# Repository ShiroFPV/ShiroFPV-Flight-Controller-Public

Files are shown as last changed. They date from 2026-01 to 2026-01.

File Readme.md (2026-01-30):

## 📖 Credits 
This project was heavily inspired by the amazing work of AcciFPV. Their creativity and open sharing within the FPV community motivated me to start developing my own hardware. While this design is fully original, AcciFPV’s approach and passion for innovation definitely sparked many of the ideas behind it. Huge thanks to them for contributing so much to the FPV scene — check out their projects for more awesome stuff!
[Github](https://gist.github.com/jesuslg123)
[AcciFPV Flight Controller](https://oshwlab.com/jesuslg123/f4-v1)

## 📖 Documentation

This repository includes a full website with detailed documentation. You can view the live documentation here:

[Website](https://shirofpv.github.io/ShiroFPV-Flight-Controller-Public/Website/index.html)

The documentation covers:
* **Hardware Specifications:** A breakdown of components.
* **Software & Firmware:** Information on compatible firmware (Betaflight) and how to get the latest builds.
* **Setup Guide:** A step-by-step guide to flashing firmware, and getting your drone in the air.

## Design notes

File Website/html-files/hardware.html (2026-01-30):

ShiroFPV

# Hardware Specifications

Technical details and component information

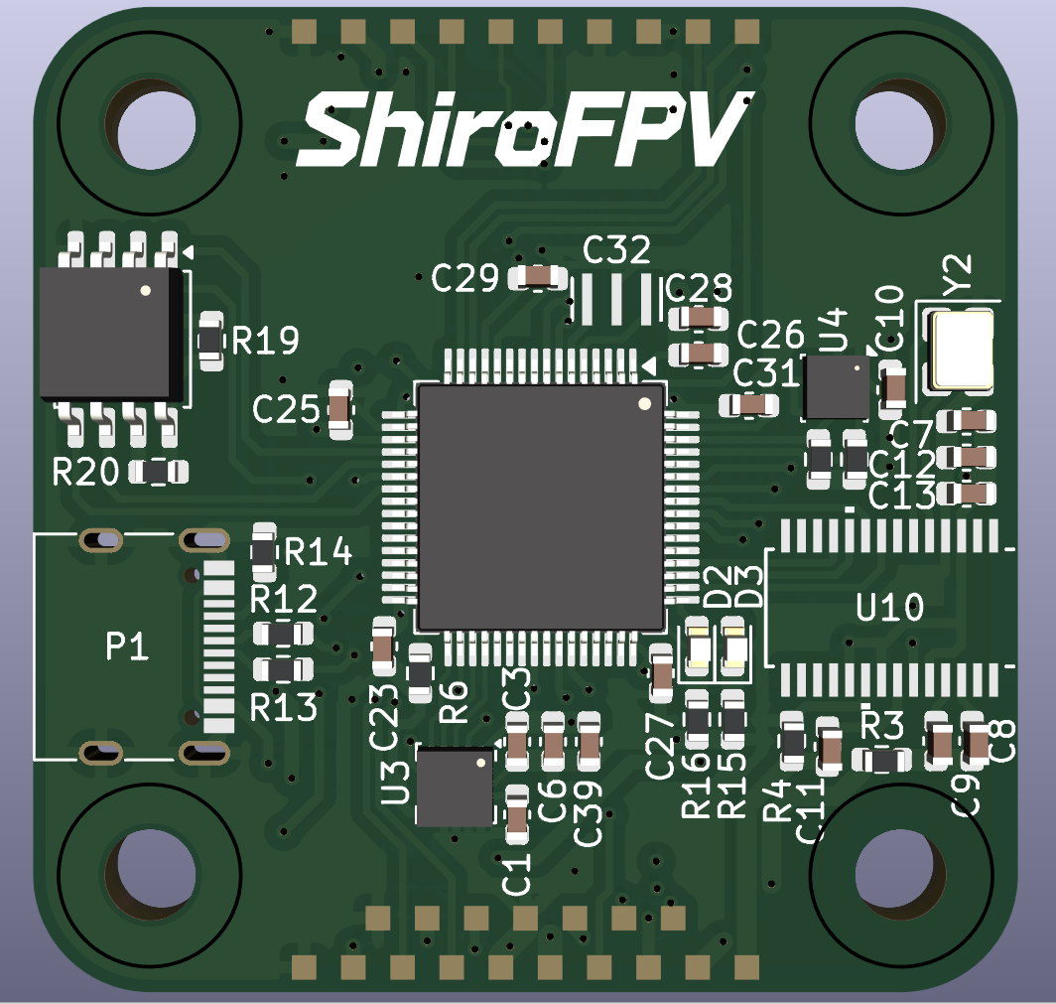
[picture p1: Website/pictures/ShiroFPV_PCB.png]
Betaflight Logo


### Microcontroller

High-performance MCU with fast processing capabilities for real-time flight control

### IMU Sensor

Precision gyroscope and barometer for accurate orientation tracking

### Form Factor

Compact design compatible with modern FPV frames (30x30mm mounting)

### Input Voltage

Wide voltage input range with onboard regulation for stable operation

## Key Features

- High-speed gyro: Fast sampling rates for smooth, precise control
- Onboard voltage regulation: Stable power delivery to all components
- USB connectivity: Easy configuration and firmware updates
- Multiple UART ports: Connect receivers, GPS, telemetry, and more
- PWM outputs: Drive ESCs with configurable protocols
- LED indicators: Visual status feedback for easy troubleshooting
- Mounting holes: Standard mounting pattern for easy installation
- Durable PCB: High-quality materials for long-term reliability

## PCB Design

The ShiroFPV flight controller features a carefully optimized PCB layout with attention to signal integrity, power distribution, and electromagnetic compatibility. All design files are available on GitHub for those interested in manufacturing their own boards or learning from the design.

## Build Quality

Each component is carefully selected for performance and reliability. The board undergoes thorough testing to ensure it meets high standards for FPV flight applications.

© 2026 ShiroFPV. Open Source Hardware Project.

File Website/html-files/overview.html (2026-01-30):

ShiroFPV

# Overview

Everything you need to know about the ShiroFPV Flight Controller

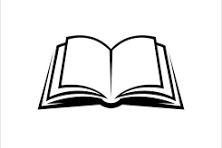
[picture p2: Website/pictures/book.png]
Book


## What is ShiroFPV?

The ShiroFPV Flight Controller is a high-performance, open-source flight control system designed by an FPV pilot for FPV pilots. Built with modern components and support for the Betaflight firmware, it delivers exceptional flight characteristics and reliability.

Key Philosophy: ShiroFPV combines professional-grade performance with open-source accessibility, allowing pilots to fully understand and customize their flight control system.

## Core Features

- High-Speed Processing: Fast loop times for precise control and minimal latency
- Robust Design: Built to withstand crashes and harsh flying conditions
- Betaflight Compatible: Full support for the most popular FPV firmware
- Compact Form Factor: Optimized size for modern racing and freestyle frames
- Open Source: Complete hardware designs and documentation available on GitHub
- Community Driven: Active development with regular updates and improvements

## Target Audience

ShiroFPV is designed for:

- FPV racing pilots seeking competitive performance
- Freestyle pilots who demand reliable, responsive control
- DIY enthusiasts interested in open-source hardware
- Developers wanting to customize and extend flight controller capabilities

## Project Goals

The ShiroFPV project aims to provide a completely transparent, high-quality flight controller that empowers users to understand, modify, and improve their flight systems. By keeping everything open source, we foster innovation and community collaboration.

© 2026 ShiroFPV. Open Source Hardware Project.

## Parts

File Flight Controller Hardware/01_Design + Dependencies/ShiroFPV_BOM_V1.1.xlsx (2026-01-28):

Quantity | Footprint | Supplier | Supplier Part Number | Manufacturer | Manufacturer Part Number
18 | Capacitor_SMD:C_0603_1608Metric | LCSC | C327087 | YAGEO | CC0603JRX7R8BB104
1 | Capacitor_SMD:C_0603_1608Metric | LCSC | C3894265 | KEMET | C0603C103F3GECAUTO
2 | Capacitor_SMD:C_0603_1608Metric | LCSC | C106248 | GENERIC | 1uF_0603_X7R_16V
4 | Capacitor_SMD:C_0603_1608Metric | LCSC | C403725 | muRata | GRM31CR61E476ME44L
2 | Capacitor_SMD:C_1206_3216Metric | LCSC | C89632 | SAMSUNG | CL31B106KBHNNNE
1 | Capacitor_SMD:C_0603_1608Metric | LCSC | C519513 | YAGEO | CC0603JRX7R9BB101
1 | Capacitor_SMD:C_0603_1608Metric | LCSC | C519515 | YAGEO | CC0603JRX7R9BB151
1 | All_Own_Symbols:8MHz-Osciallator.kicad_sym | LCSC | C907975 | muRata | CSTNE8M00G520000R0
1 | Capacitor_SMD:C_0603_1608Metric | LCSC | C106213 | YEGEO | CC0603KRX5R6BB225
1 | Diode_SMD:D_SOD-323_HandSoldering | LCSC | C131828 | LRC | LM3Z10VT1G
1 | LED_SMD:LED_0603_1608Metric | LCSC | C72038 | EVERLIGHT | 19-213/Y2C-CQ2R2L/3T(CY)
1 | LED_SMD:LED_0603_1608Metric | LCSC | C2986058 | EVERLIGHT | 19-217/BHC-ZL1M2RY/6T
1 | Package_TO_SOT_SMD:SOT-23 | LCSC | C552889 | Nexperia | PMEG4005CT,215
1 | Fuse:Fuse_1206_3216Metric | LCSC | C163128 | TA-I Tech | CFS12V3T5R0
1 | Inductor_SMD:L_APV_APH0412 | LCSC | C351093 | YJYCOIN | YSPI0420-100M
1 | Inductor_SMD:L_APV_APH0412 | LCSC | C497861 | YJYCOIN | YSPI0530-150M
1 | Connector_USB:USB_C_Receptacle_G-Switch_GT-USB-7010ASV | LCSC | C2988369 | G-Switch | GT-USB-7010ASV
1 | Package_TO_SOT_SMD:SOT-23 | LCSC | C15127 | Alpha & Omega Semicon | AO3401A
1 | Package_TO_SOT_SMD:SOT-23 | LCSC | C20917 | Alpha & Omega Semicon | AO3400A
1 | Package_TO_SOT_SMD:SOT-323_SC-70 | LCSC | C148104 | CJ | BC817W
3 | Resistor_SMD:R_0603_1608Metric | LCSC | C14675 | YAGEO | RC0603FR-07100KL
1 | Resistor_SMD:R_0603_1608Metric | LCSC | C22548 | YAGEO | RC0603FR-0712K3L
2 | Resistor_SMD:R_0603_1608Metric | LCSC | C112309 | YAGEO | RC0603FR-0775RL
6 | Resistor_SMD:R_0603_1608Metric | LCSC | C98220 | YAGEO | RC0603FR-0710KL
1 | Resistor_SMD:R_0603_1608Metric | LCSC | C114631 | YAGEO | RC0603FR-076K2L
2 | Resistor_SMD:R_0603_1608Metric | LCSC | C107701 | YAGEO | RC0603FR-0722RL
1 | Resistor_SMD:R_0603_1608Metric | LCSC | C105580 | YAGEO | RC0603FR-075K1L
2 | Resistor_SMD:R_0603_1608Metric | LCSC | C114608 | YAGEO | RC0603FR-07150RL
2 | Resistor_SMD:R_0603_1608Metric | LCSC | C114662 | YAGEO | RC0603FR-072K2L
1 | Resistor_SMD:R_0603_1608Metric | LCSC | C105576 | YAGEO | RC0603FR-072KL
1 | Resistor_SMD:R_0603_1608Metric | LCSC | C99782 | YAGEO | RC0603FR-074K7L
1 | Resistor_SMD:R_0603_1608Metric | LCSC | C114610 | YAGEO | RC0603FR-0718KL
1 | Package_QFP:LQFP-64_10x10mm_P0.5mm | LCSC | C3029577 | ARTERY | AT32F435RGT7
1 | Package_LGA:LGA-16_3x3mm_P0.5mm_LayoutBorder3x5y | LCSC | C97633 | TDK InvenSense | ICM-20602
1 | Package_LGA:Bosch_LGA-8_2.5x2.5mm_P0.65mm_ClockwisePinNumbering | LCSC | C92489 | BOSCH | BME280
2 | Package_TO_SOT_SMD:SOT-23-6 | LCSC | C311983 | TI | TPS54302DDCR
1 | Package_TO_SOT_SMD:SOT-23-5 | LCSC | C47773 | RICHTEK | RT9013-33GB
1 | Package_SO:SOIC-8_5.3x5.3mm_P1.27mm | LCSC | C97521 | Winbond | W25Q128JVSIQ
1 | All_Own_Symbols:AT7456 | LCSC | C82351 | ZHONGKEWEI | AT7456E
1 | Crystal:Crystal_SMD_3225-4Pin_3.2x2.5mm | LCSC | C164057 | ZHONGKEWEI | TAXM27M4RFBCCT2T

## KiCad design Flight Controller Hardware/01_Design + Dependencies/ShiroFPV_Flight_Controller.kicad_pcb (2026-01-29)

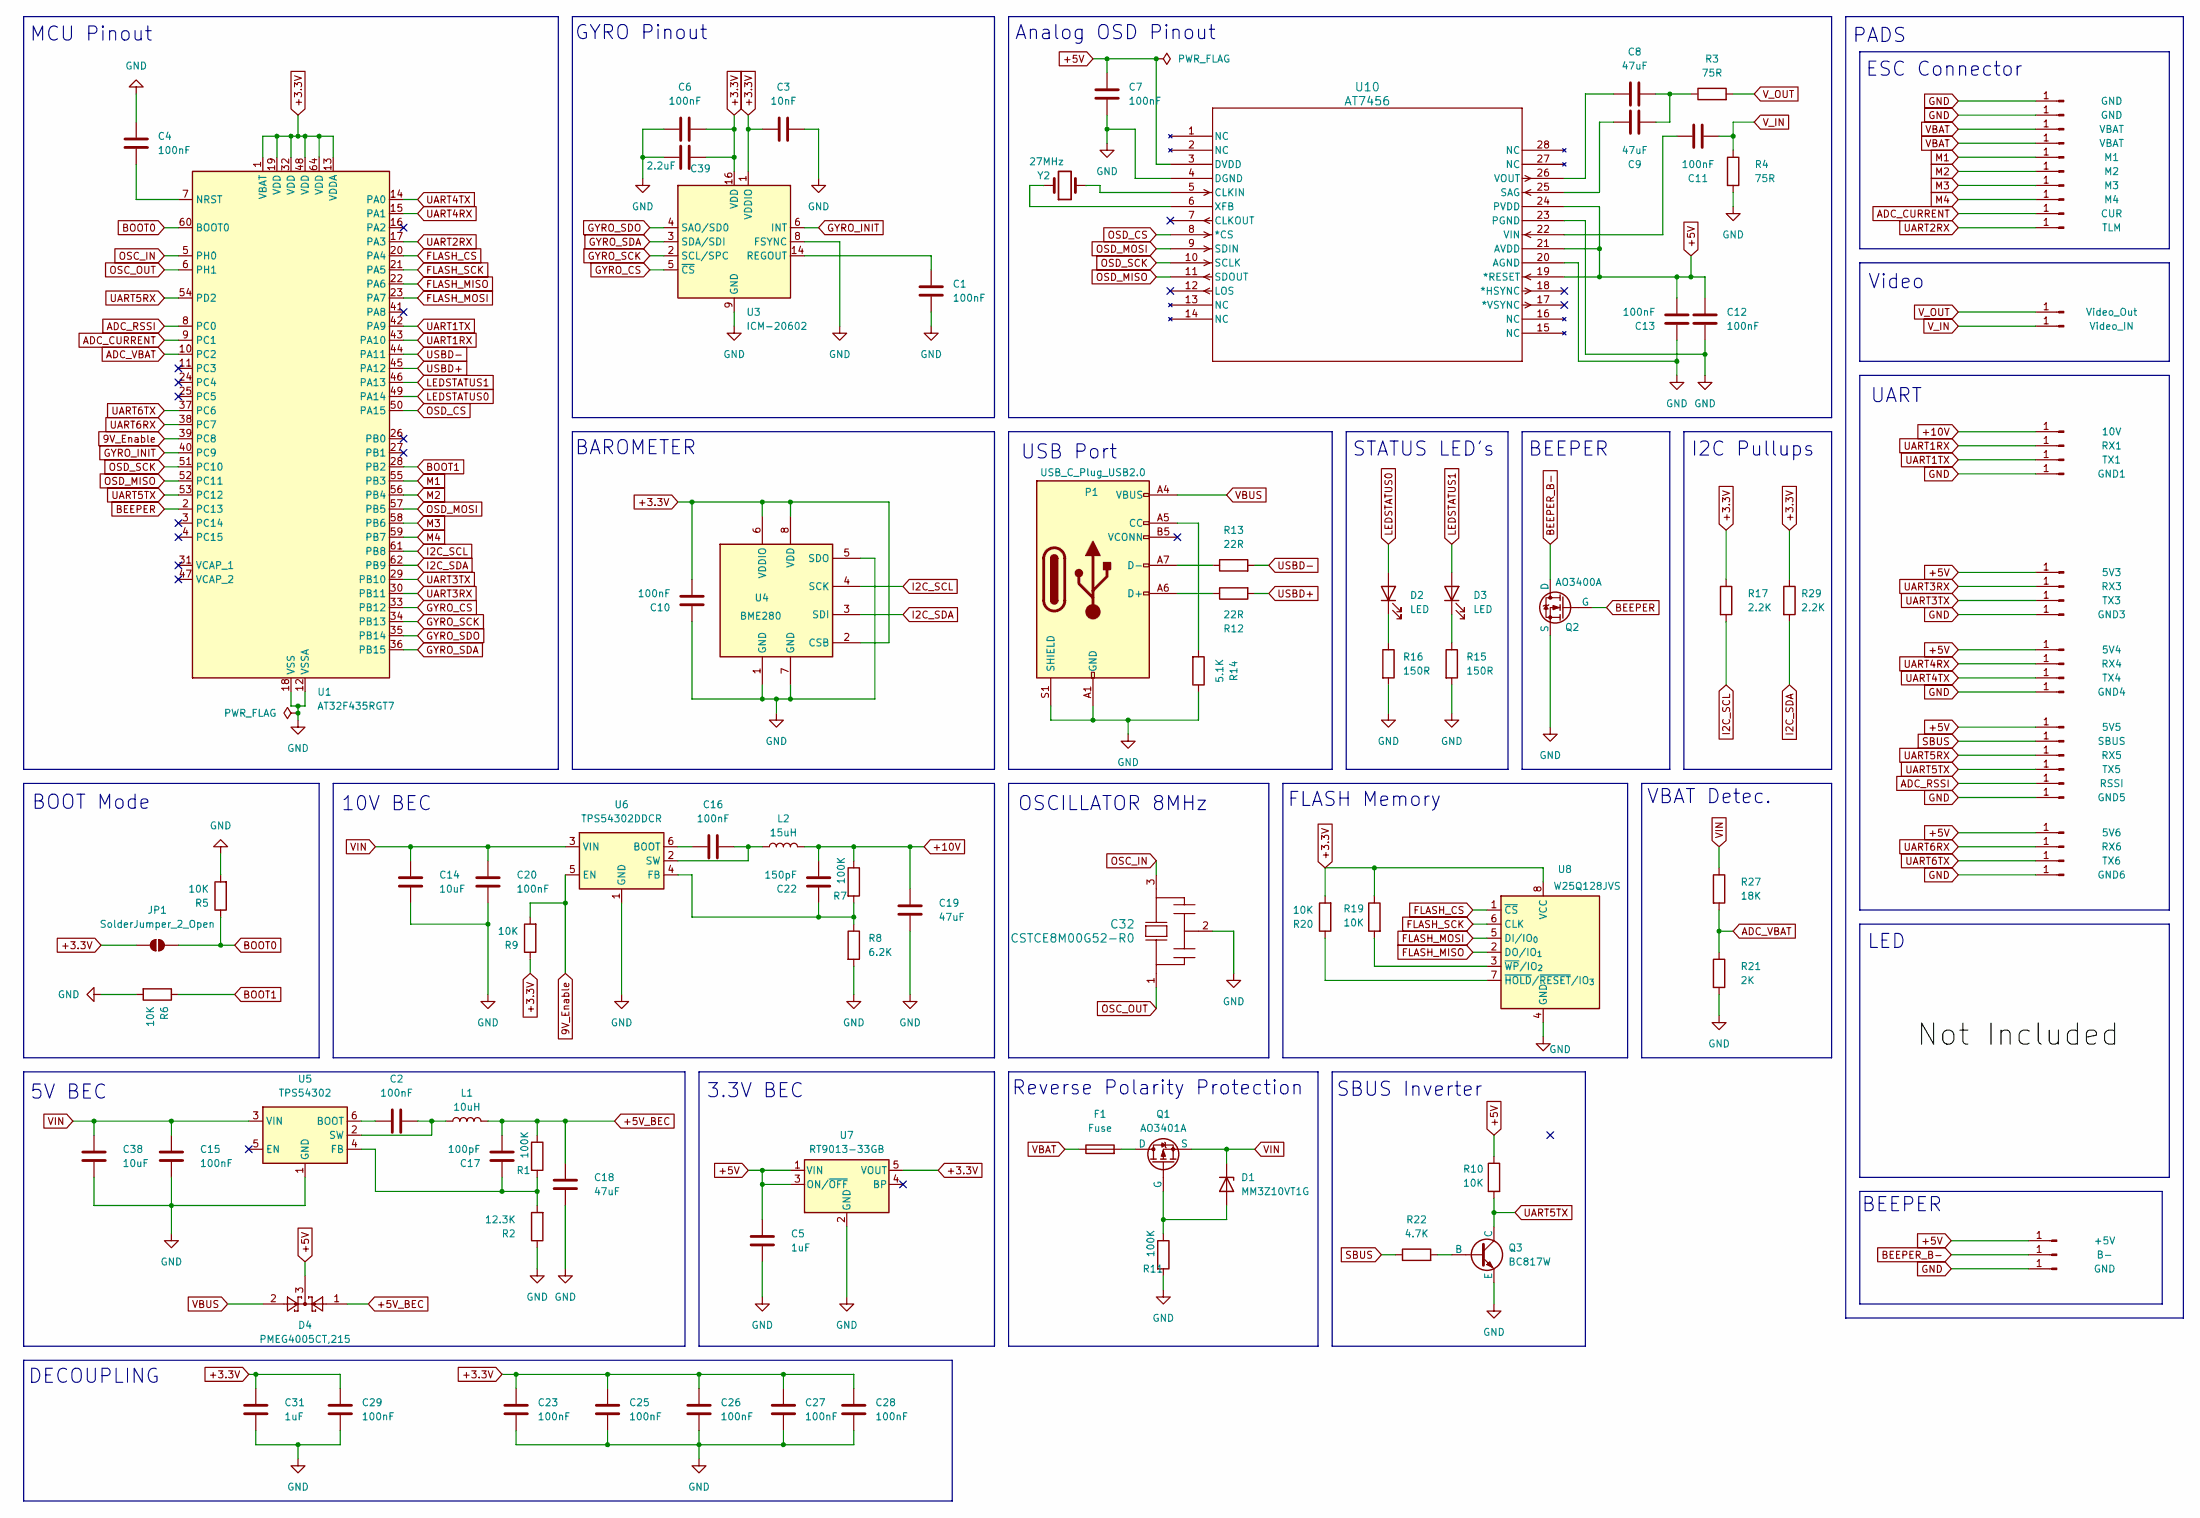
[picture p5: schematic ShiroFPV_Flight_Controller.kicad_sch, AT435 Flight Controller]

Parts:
C1, C2, C4, C6, C7, C10, C11, C12, C13, C15, C16, C20, C23, C25, C26, C27, C28, C29: 100nF; C_0603_1608Metric; MPN CC0603JRX7R8BB104
C3: 10nF; C_0603_1608Metric; MPN C0603C103F3GECAUTO
C5, C31: 1uF; C_0603_1608Metric; MPN 1uF_0603_X7R_16V
C8, C9: 47uF; C_0603_1608Metric; MPN GRM31CR61E476ME44L
C14, C38: 10uF; C_1206_3216Metric; MPN CL31B106KBHNNNE
C17: 100pF; C_0603_1608Metric; MPN CC0603JRX7R9BB101
C18, C19: 47uF; C_1206_3216Metric; MPN GRM31CR61E476ME44L
C22: 150pF; C_0603_1608Metric; MPN CC0603JRX7R9BB151
C32: CSTCE8M00G52-R0; 8MHz-Osciallator.kicad_sym; MPN CSTNE8M00G520000R0
C39: 2.2uF; C_0603_1608Metric; MPN CC0603KRX5R6BB225
D1: MM3Z10VT1G; D_SOD-323_HandSoldering; MPN LM3Z10VT1G
D2, D3: LED; LED_0603_1608Metric
D4: PMEG4005CT,215; SOT-23
F1: Fuse; Fuse_1206_3216Metric
J1, J2, J46: GND; TestPoint_Pad_1.0x1.0mm
J3, J4: VBAT; TestPoint_Pad_1.0x1.0mm
J5: M1; TestPoint_Pad_1.0x1.0mm
J6: M2; TestPoint_Pad_1.0x1.0mm
J7: M3; TestPoint_Pad_1.0x1.0mm
J8: M4; TestPoint_Pad_1.0x1.0mm
J9: CUR; TestPoint_Pad_1.0x1.0mm
J10: TLM; TestPoint_Pad_1.0x1.0mm
J11: Video_Out; TestPoint_Pad_1.0x1.0mm
J12: Video_IN; TestPoint_Pad_1.0x1.0mm
J13: 5V3; TestPoint_Pad_1.0x1.0mm
J14: RX3; TestPoint_Pad_1.0x1.0mm
J15: TX3; TestPoint_Pad_1.0x1.0mm
J16: GND3; TestPoint_Pad_1.0x1.0mm
J17: 5V4; TestPoint_Pad_1.0x1.0mm
J18: RX4; TestPoint_Pad_1.0x1.0mm
J19: TX4; TestPoint_Pad_1.0x1.0mm
J20: GND4; TestPoint_Pad_1.0x1.0mm
J24: +5V; TestPoint_Pad_1.0x1.0mm
J25: RSSI; TestPoint_Pad_1.0x1.0mm
J26: GND5; TestPoint_Pad_1.0x1.0mm
J29: SBUS; TestPoint_Pad_1.0x1.0mm
J30: 5V5; TestPoint_Pad_1.0x1.0mm
J31: RX5; TestPoint_Pad_1.0x1.0mm
J32: TX5; TestPoint_Pad_1.0x1.0mm
J33: RX6; TestPoint_Pad_1.0x1.0mm
J34: 5V6; TestPoint_Pad_1.0x1.0mm
J35: GND6; TestPoint_Pad_1.0x1.0mm
J36: TX6; TestPoint_Pad_1.0x1.0mm
J37: 10V; TestPoint_Pad_1.0x1.0mm
J38: RX1; TestPoint_Pad_1.0x1.0mm
J39: TX1; TestPoint_Pad_1.0x1.0mm
J40: GND1; TestPoint_Pad_1.0x1.0mm
J42: B-; TestPoint_Pad_1.0x1.0mm
JP1: SolderJumper_2_Open; SolderJumper-2_P1.3mm_Open_Pad1.0x1.5mm
L1: 10uH; L_APV_APH0412
L2: 15uH; L_APV_APH0412; MPN YSPI0530-150M
P1: USB_C_Plug_USB2.0; USB_C_Receptacle_G-Switch_GT-USB-7010ASV; MPN GT-USB-7010ASV
Q1: AO3401A; SOT-23
Q2: AO3400A; SOT-23
Q3: BC817W; SOT-323_SC-70
R1, R7, R11: 100K; R_0603_1608Metric; MPN RC0603FR-07100KL
R2: 12.3K; R_0603_1608Metric; MPN RC0603FR-0712K3L
R3, R4: 75R; R_0603_1608Metric; MPN RC0603FR-0775RL
R5, R6, R9, R10, R19, R20: 10K; R_0603_1608Metric; MPN RC0603FR-0710KL
R8: 6.2K; R_0603_1608Metric; MPN RC0603FR-076K2L
R12, R13: 22R; R_0603_1608Metric; MPN RC0603FR-0722RL
R14: 5.1K; R_0603_1608Metric; MPN RC0603FR-075K1L
R15, R16: 150R; R_0603_1608Metric; MPN RC0603FR-07150RL
R17, R29: 2.2K; R_0603_1608Metric; MPN RC0603FR-072K2L
R21: 2K; R_0603_1608Metric; MPN RC0603FR-072KL
R22: 4.7K; R_0603_1608Metric; MPN RC0603FR-074K7L
R27: 18K; R_0603_1608Metric; MPN RC0603FR-0718KL
U1: AT32F435RGT7; LQFP-64_10x10mm_P0.5mm
U3: ICM-20602; LGA-16_3x3mm_P0.5mm_LayoutBorder3x5y; MPN ICM-20602
U4: BME280; Bosch_LGA-8_2.5x2.5mm_P0.65mm_ClockwisePinNumbering; MPN BME280
U5: TPS54302; SOT-23-6; MPN TPS54302DDCR
U6: TPS54302DDCR; SOT-23-6; MPN TPS54302DDCR
U7: RT9013-33GB; SOT-23-5; MPN RT9013-33GB
U8: W25Q128JVS; SOIC-8_5.3x5.3mm_P1.27mm; MPN W25Q128JVSIQ
U10: AT7456; MPN AT7456E
Y2: 27MHz; Crystal_SMD_3225-4Pin_3.2x2.5mm

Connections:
9V_Enable: R9.2, U1.39 (PC8), U6.5 (EN)
+3.3V: C3.1, C6.2, C10.1, C23.1, C25.1, C26.1, C27.1, C28.1, C29.1, C31.1, C39.1, JP1.1 (A), R9.1, R17.1, R19.1, R20.2, R29.1, U1.1 (VBAT), U1.13 (VDDA), U1.19 (VDD), U1.32 (VDD), U1.48 (VDD), U1.64 (VDD), U3.1 (VDDIO), U3.16 (VDD), U4.2 (CSB), U4.6 (VDDIO), U4.8 (VDD), U7.5 (VOUT), U8.8 (VCC)
+5V: C5.1, C7.2, C12.2, C13.1, D4.3, J13.1, J17.1, J24.1, J30.1, J34.1, R10.1, U7.1 (VIN), U7.3 (ON/~OFF), U10.3 (DVDD), U10.19 (*RESET), U10.21 (AVDD), U10.24 (PVDD)
+5V_BEC: C17.1, C18.1, D4.1, L1.2, R1.1
+10V: C19.1, C22.1, J37.1, L2.2, R7.1
ADC_CURRENT: J9.1, U1.9 (PC1)
ADC_RSSI: J25.1, U1.8 (PC0)
ADC_VBAT: R21.1, R27.2, U1.10 (PC2)
BEEPER: Q2.2 (G), U1.2 (PC13)
BEEPER_B-: J42.1, Q2.1 (D)
BOOT0: JP1.2 (B), R5.1, U1.60 (BOOT0)
BOOT1: R6.1, U1.28 (PB2)
FLASH_CS: U1.20 (PA4), U8.1 (~CS)
FLASH_MISO: U1.22 (PA6), U8.2 (DO/IO_{1})
FLASH_MOSI: U1.23 (PA7), U8.5 (DI/IO_{0})
FLASH_SCK: U1.21 (PA5), U8.6 (CLK)
GND: C1.1, C3.2, C4.1, C5.2, C6.1, C7.1, C10.2, C12.1, C13.2, C14.2, C15.2, C18.2, C19.2, C20.2, C23.2, C25.2, C26.2, C27.2, C28.2, C29.2, C31.2, C32.2, C38.2, C39.2, J1.1, J2.1, J16.1, J20.1, J26.1, J35.1, J40.1, J46.1, P1.A1 (GND), P1.A12 (GND), P1.B1 (GND), P1.B12 (GND), P1.S1 (SHIELD), Q2.3 (S), Q3.3 (E), R2.1, R4.2, R5.2, R6.2, R8.2, R11.2, R14.1, R15.2, R16.2, R21.2, U1.12 (VSSA), U1.18 (VSS), U1.63 (VSS), U3.8 (FSYNC), U3.9 (GND), U3.10 (GND), U3.11 (GND), U3.12 (GND), U3.13 (GND), U3.15 (GND), U4.1 (GND), U4.5 (SDO), U4.7 (GND), U5.1 (GND), U6.1 (GND), U7.2 (GND), U8.4 (GND), U10.4 (DGND), U10.20 (AGND), U10.23 (PGND), Y2.3, Y2.4
GYRO_CS: U1.33 (PB12), U3.5 (~CS)
GYRO_INIT: U1.40 (PC9), U3.6 (INT)
GYRO_SCK: U1.34 (PB13), U3.2 (SCL/SPC)
GYRO_SDA: U1.36 (PB15), U3.3 (SDA/SDI)
GYRO_SDO: U1.35 (PB14), U3.4 (SAO/SD0)
I2C_SCL: R17.2, U1.61 (PB8), U4.4 (SCK)
I2C_SDA: R29.2, U1.62 (PB9), U4.3 (SDI)
LEDSTATUS0: D2.2 (A), U1.49 (PA14)
LEDSTATUS1: D3.2 (A), U1.46 (PA13)
M1: J5.1, U1.55 (PB3)
M2: J6.1, U1.56 (PB4)
M3: J7.1, U1.58 (PB6)
M4: J8.1, U1.59 (PB7)
unnamed: C8.2, C9.2, R3.1
unnamed: D1.2 (A), Q1.2 (G), R11.1
unnamed: D2.1 (K), R16.1
unnamed: D3.1 (K), R15.1
unnamed: P1.A5 (CC), R14.2
unnamed: P1.A6 (D+), R12.1
unnamed: P1.A7 (D-), R13.1
unnamed: F1.2, Q1.1 (D)
unnamed: Q3.2 (B), R22.2
unnamed: C4.2, U1.7 (NRST)
unnamed: C1.2, U3.14 (REGOUT)
unnamed: C2.2, U5.6 (BOOT)
unnamed: C17.2, R1.2, R2.2, U5.4 (FB)
unnamed: C2.1, L1.1, U5.2 (SW)
unnamed: C16.2, U6.6 (BOOT)
unnamed: C22.2, R7.2, R8.1, U6.4 (FB)
unnamed: C16.1, L2.1, U6.2 (SW)
unnamed: R20.1, U8.7 (~HOLD/~RESET/IO_{3})
unnamed: R19.2, U8.3 (~WP/IO_{2})
unnamed: U10.5 (CLKIN), Y2.2
unnamed: C9.1, U10.25 (SAG)
unnamed: C11.1, U10.22 (VIN)
unnamed: C8.1, U10.26 (VOUT)
unnamed: U10.6 (XFB), Y2.1
OSC_IN: C32.3, U1.5 (PH0)
OSC_OUT: C32.1, U1.6 (PH1)
OSD_CS: U1.50 (PA15), U10.8 (*CS)
OSD_MISO: U1.52 (PC11), U10.11 (SDOUT)
OSD_MOSI: U1.57 (PB5), U10.9 (SDIN)
OSD_SCK: U1.51 (PC10), U10.10 (SCLK)
SBUS: J29.1, R22.1
UART1RX: J38.1, U1.43 (PA10)
UART1TX: J39.1, U1.42 (PA9)
UART2RX: J10.1, U1.17 (PA3)
UART3RX: J14.1, U1.30 (PB11)
UART3TX: J15.1, U1.29 (PB10)
UART4RX: J18.1, U1.15 (PA1)
UART4TX: J19.1, U1.14 (PA0)
UART5RX: J31.1, U1.54 (PD2)
UART5TX: J32.1, Q3.1 (C), R10.2, U1.53 (PC12)
UART6RX: J33.1, U1.38 (PC7)
UART6TX: J36.1, U1.37 (PC6)
USBD+: R12.2, U1.45 (PA12)
USBD-: R13.2, U1.44 (PA11)
VBAT: F1.1, J3.1, J4.1
VBUS: D4.2, P1.A4 (VBUS), P1.A9 (VBUS), P1.B4 (VBUS), P1.B9 (VBUS)
VIN: C14.1, C15.1, C20.1, C38.1, D1.1 (K), Q1.3 (S), R27.1, U5.3 (VIN), U6.3 (VIN)
V_IN: C11.2, J12.1, R4.1
V_OUT: J11.1, R3.2

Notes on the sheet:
DECOUPLING
ESC Connector
OSCILLATOR 8MHz
LED
5V BEC
VBAT Detec.
UART
FLASH Memory
PADS
BAROMETER
BEEPER
Video
STATUS LED's
I2C Pullups
BEEPER
BOOT Mode
MCU Pinout
Analog OSD Pinout
10V BEC
GYRO Pinout
3.3V BEC
USB Port
Reverse Polarity Protection
SBUS Inverter

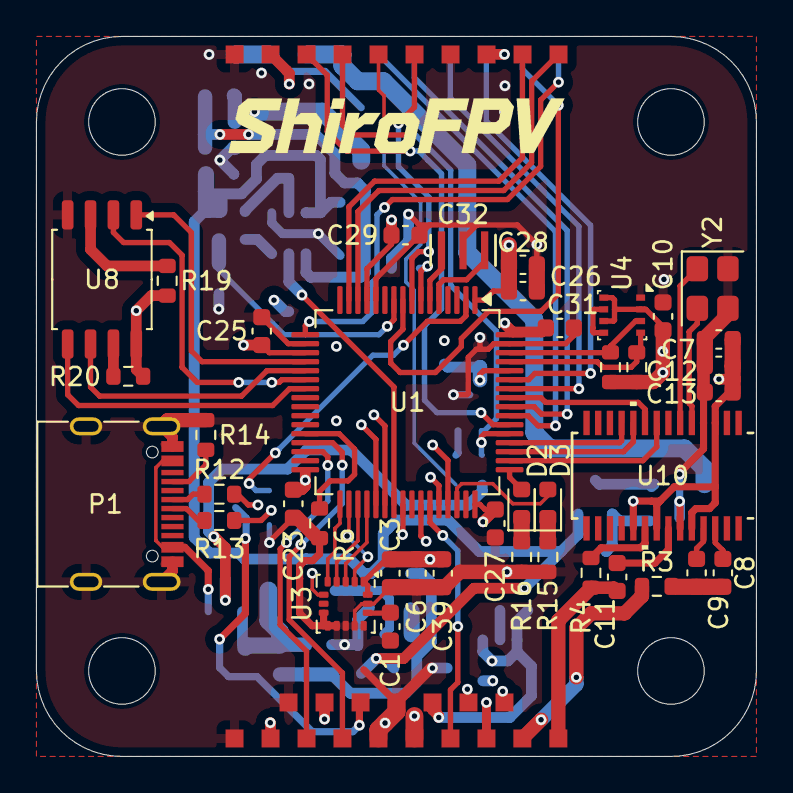
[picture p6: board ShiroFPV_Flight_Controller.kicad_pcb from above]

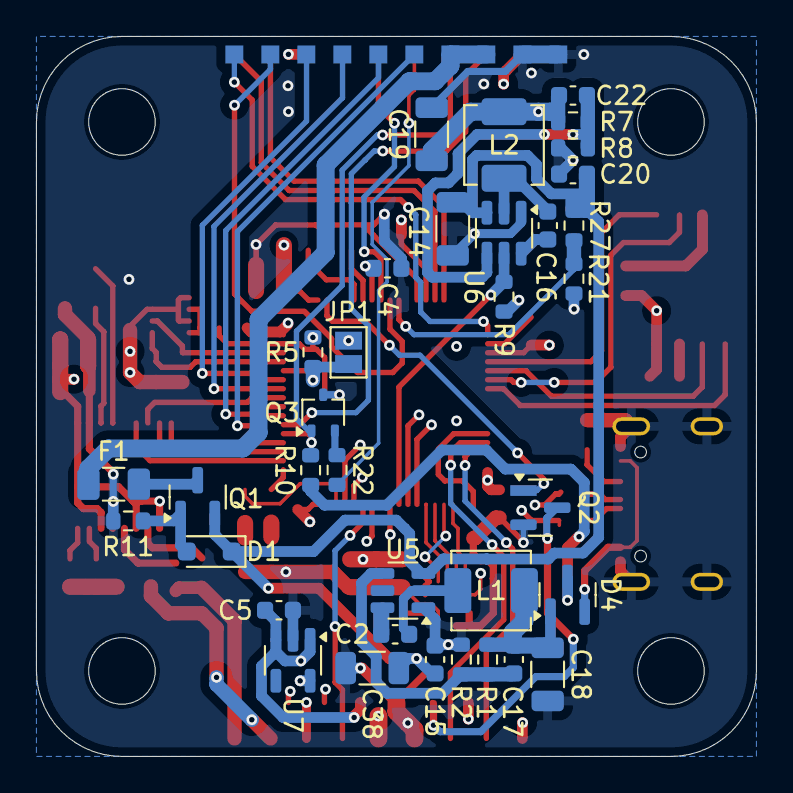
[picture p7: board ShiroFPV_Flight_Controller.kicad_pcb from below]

Board: 4 copper layers, 40.0 x 40.0 mm, 112 parts (45 on the bottom side), 79 nets.

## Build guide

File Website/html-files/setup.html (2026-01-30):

ShiroFPV

# Setup Guide

Step-by-step instructions to get your ShiroFPV flight controller ready to fly

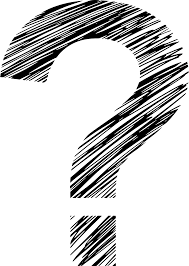
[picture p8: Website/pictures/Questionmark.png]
Betaflight Logo


## Prerequisites

### Before you begin, make sure you have the following:

- ShiroFPV flight controller
- USB cable (appropriate type for your FC)
- Computer with Betaflight Configurator installed
- Latest firmware hex file downloaded from GitHub
- Drone frame with motors and ESCs installed

### Step 1: Install Betaflight Configurator

Download and install Betaflight Configurator from betaflight.com/download. Choose the appropriate version for your operating system (Windows, macOS, or Linux).

### Step 2: Download Firmware

Visit the GitHub releases page (https://github.com/ShiroFPV/ShiroFPV-Flight-Controller-Public/releases) and download the latest firmware hex file for your ShiroFPV flight controller.

## Flashing the Firmware

### Step 3: Connect to Computer

1. Connect your ShiroFPV flight controller to your computer using a USB cable (If you plan on Flashing the Device you may need an External Powersource like a Lipo)
2. Open Betaflight Configurator
3. Wait for the computer to recognize the device

### Step 4: Enter DFU Mode

1. In Betaflight Configurator, navigate to the "Firmware Flasher" tab
2. If the FC doesn't automatically enter DFU mode, you may bridge the Boot Solder pads wich are found on the underside of the FC, while plugging in USB
3. Verify that the configurator detects the board in DFU mode

Important: Make sure to select "Full chip erase" when flashing firmware for the first time or when switching between major versions.

### Step 5: Flash Firmware

1. Select "Load Firmware [Local]" and choose the hex file you downloaded
2. Enable "Full chip erase" (recommended for first flash)
3. Click "Flash Firmware" and wait for the process to complete
4. Do not disconnect USB during flashing

## Initial Configuration

### Step 6: Connect and Configure

1. After flashing completes, disconnect and reconnect the USB cable
2. Click "Connect" in Betaflight Configurator
3. Navigate to the "Setup" tab to verify the board is working correctly
4. Check that the 3D model responds to FC movement

### Step 7: Basic Configuration

1. Ports Tab: Configure UART ports for your receiver, GPS, or other peripherals
2. Configuration Tab: Set motor protocol, ESC type, and other basic settings
3. Receiver Tab: Configure your radio receiver and verify stick inputs
4. Modes Tab: Set up ARM switch and flight modes
5. Motors Tab: Test motor direction and order (props off!)

Safety First: Always remove propellers when testing motors and configuring your flight controller!

## Final Steps

### Step 8: Sensor Calibration

1. Place the drone on a flat, level surface
2. Go to the "Setup" tab and click "Calibrate Accelerometer"
3. Wait for calibration to complete
4. Test that the level indicator is accurate

### Step 9: PID Tuning (Optional)

For initial flights, the default PID values should work well. After some test flights, you can fine-tune the PID values in the "PID Tuning" tab to optimize flight characteristics for your specific setup.

Ready to Fly! Your ShiroFPV flight controller is now configured and ready for test flights. Always perform a safety check before flying and start with low-throttle hover tests in a safe area.

## Troubleshooting

- FC not connecting: Try a different USB cable or port. Some cables are charge-only.
- DFU mode not working: Look for a boot button on the FC or short the boot pads while connecting USB.
- Motors not spinning: Check motor protocol settings, ESC connections, and motor direction.
- Receiver not binding: Verify correct UART configuration and receiver protocol settings.

For additional support, visit the GitHub repository issues page or join the FPV community forums.

© 2026 ShiroFPV. Open Source Hardware Project.

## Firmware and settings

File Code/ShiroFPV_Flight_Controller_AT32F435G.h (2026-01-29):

#pragma once

#define TARGET_BOARD_IDENTIFIER "ShiroFPV_AT32F435G" // Shiro AT435
#define FC_TARGET_MCU AT32F435G

#define BOARD_NAME "ShiroFPV_AT435G"
#define MANUFACTURER_ID CUSTOM

// Features
#define USE_ACC
#define USE_GYRO
#define USE_BARO
#define USE_FLASH
#define USE_MAX7456
#define USE_ADC

// Sensors
#define USE_GYRO_SPI_ICM20602
#define USE_ACC_SPI_ICM20602
#define USE_BARO_BME280
#define USE_FLASH_W25Q128FV

// IO
#define LED0_PIN PA14
#define LED1_PIN PA13
#define BEEPER_PIN PC13
#define BEEPER_INVERTED

// SPI Gyro SPI4
#define USE_SPI_GYRO
#define GYRO_1_EXTI_PIN PC9
#define GYRO_1_CS_PIN PB12
#define GYRO_1_SPI_INSTANCE SPI4
#define GYRO_1_ALIGN CW0_DEG
#define GYRO_1_ALIGN_YAW 1800

#define SPI1_SCK_PIN PA5
#define SPI1_SDI_PIN PA6
#define SPI1_SDO_PIN PA7

#define SPI2_SCK_PIN PB13  // Flash
#define SPI2_SDI_PIN PB14
#define SPI2_SDO_PIN PB15
#define FLASH_CS_PIN PB12
#define FLASH_SPI_INSTANCE SPI2

#define SPI3_SCK_PIN PC10  // OSD
#define SPI3_SDI_PIN PC11
#define SPI3_SDO_PIN PB5
#define MAX7456_SPI_CS_PIN PA15
#define MAX7456_SPI_INSTANCE SPI3

// ADC
#define ADC_VBAT_PIN PC1
#define ADC_RSSI_PIN PC2
#define ADC_CURR_PIN PC3
#define ADC_INSTANCE ADC3
#define ADC1_DMA_OPT 11

// UARTs (Netlist-match)
#define UART1_TX_PIN PA9  // J39
#define UART1_RX_PIN PA10 // J38
#define UART2_TX_PIN PA2
#define UART2_RX_PIN PA3
#define UART3_TX_PIN PB10 // TLM J15?
#define UART3_RX_PIN PB11 // J14
#define UART4_TX_PIN PA0
#define UART4_RX_PIN PA1
#define UART5_TX_PIN PC12
#define UART5_RX_PIN PD2
#define UART6_TX_PIN PC6
#define UART6_RX_PIN PC7

// TIMERS & MOTORS (Netlist J5-8)
#define TIMER_PIN_MAPPING \
    TIMER_PIN_MAP( 0, PB3 , 1, 0) \
    TIMER_PIN_MAP( 1, PB4 , 1, 0) \
    TIMER_PIN_MAP( 2, PB6 , 2, 0) \
    TIMER_PIN_MAP( 3, PB7 , 2, 0) \
    TIMER_PIN_MAP( 4, PC8 , 2, 0)

#define MOTOR1_PIN PB3
#define MOTOR2_PIN PB4
#define MOTOR3_PIN PB6
#define MOTOR4_PIN PB7

// I2C Baro
#define BARO_I2C_INSTANCE I2CDEV_1
#define I2C1_SCL_PIN PB8
#define I2C1_SDA_PIN PB9

// PINIO
#define PINIO1_PIN PC8
#define PINIO1_BOX 40
#define PINIO1_CONFIG 129

// Defaults
#define DEFAULT_BLACKBOX_DEVICE BLACKBOX_DEVICE_FLASH
#define DEFAULT_CURRENT_METER_SOURCE CURRENT_METER_ADC
#define DEFAULT_VOLTAGE_METER_SOURCE VOLTAGE_METER_ADC
#define DEFAULT_DSHOT_BURST DSHOT_DMAR_ON

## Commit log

2026-01-28 First Push
    Pushed the first Version of the Project
    [ShiroFPV_BOM_V1.1.xlsx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]
2026-01-28 Reorganize project directory structure
    Moved hardware design and website files into new 'Flight Controller Hardware' and 'Website' directories, respectively, for improved organization.
    [ShiroFPV_BOM_V1.1.xlsx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]
2026-01-28 Fixed Mistake
    Fixed a mistake made in the Pin Config of two Mosfets.
    [ShiroFPV_Flight_Controller-BoardOutLine.gbr, ShiroFPV_Flight_Controller-BottomLayer.gbr, ShiroFPV_Flight_Controller-BottomPasteMaskLayer.gbr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]
2026-01-29 Lots of new stuff
    Added a new Website thus it not beeing finished yet.
    and updated the PCB
    [ShiroFPV_Flight_Controller.kicad_pcb]
2026-01-30 Add backups; update KiCad project files
    Add three timestamped project backup ZIPs for ShiroFPV_Flight_Controller. Update .kicad_prl to set active_layer from 0 to 2. Update .kicad_sch to remove fields_autoplaced for D2 and D3 and replace their Value fields from generic "LED" to specific component identifiers (C2986058 and C72038) with adjusted positions, keeping other properties intact. These changes keep project metadata in sync with schematic component naming and preserve recent backups.
    [ShiroFPV_Flight_Controller.kicad_sch]
